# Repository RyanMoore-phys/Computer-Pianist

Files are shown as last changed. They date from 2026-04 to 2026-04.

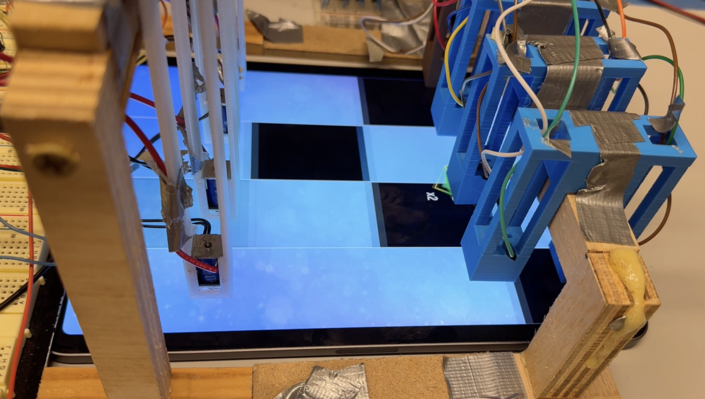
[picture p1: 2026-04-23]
Screenshot.png

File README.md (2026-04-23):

# Computer-Pianist
PianoTiles PhysicalAutoPlayer

The motivation for this project lies in the physical and biological limitations of human
reaction time compared to the processing speed of modern microcontrollers. In a typical
rhythm game environment, such as the mobile game Piano Tiles 2, a player is tasked with
identifying a visual stimulus (a black tile appearing on a white background) and reacting by physically tapping the screen.

For a human, this process involves a complex chain of biological events: optical trans-
duction in the retina, signal propagation through the optic nerve, neural processing in the visual cortex, decision-making in the frontal lobe, and finally, the propagation of motor signals to the muscles in the fingers. The average human reaction time to a visual stimulus is approximately 250 milliseconds. While this is suﬃcient for casual gameplay, it imposes a hard ”speed limit” on performance. Physically, this limits a human player to a maximum frequency of approximately 4–5 Hz (notes per second). As game diﬃculty increases, note density often exceeds this biological bandwidth, making perfect performance physiologically impossible.

This project seeks to overcome these biological constraints by replacing the human neural
pathway with an electronic circuit and software logic. By utilizing a microprocessor (Ar-
duino Uno) operating at a clock speed of 16 MHz, the ”reaction time” can be reduced from
hundreds of milliseconds to mere microseconds. Unlike human nerve impulses, which travel
at approximately 100 m/s, the internal signals of the microcontroller propagate at a significant fraction of the speed of light. This project explores the physics of optoelectronics and electromechanics to create a closed-loop system capable of playing Piano Tiles at speeds that are strictly impossible for a human player, limited only by the physical articulation time of the actuators.

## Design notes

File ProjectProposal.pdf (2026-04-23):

# Project Proposal: The Computer Pianist

### A High-Speed, Reactionary Robot for Rhythm Game Automation Physics 124

### Dylan Dahlke and Ryan Moore

### Feb 10, 2026

## 1 Motivation and Overview

### 1.1 The Limitation of Human Reflexes

The motivation for this project lies in the physical and biological limitations of human

reaction time compared to the processing speed of modern microcontrollers. In a typical

rhythm game environment, such as the mobile game Piano Tiles 2, a player is tasked with

identifying a visual stimulus (a black tile appearing on a white background) and reacting by

physically tapping the screen.

For a human, this process involves a complex chain of biological events: optical trans-

duction in the retina, signal propagation through the optic nerve, neural processing in the

visual cortex, decision-making in the frontal lobe, and finally, the propagation of motor sig-

nals to the muscles in the fingers. The average human reaction time to a visual stimulus

is approximately 250 milliseconds. While this is sufficient for casual gameplay, it imposes a

hard ”speed limit” on performance. Physically, this limits a human player to a maximum

frequency of approximately 4–5 Hz (notes per second). As game difficulty increases, note

density often exceeds this biological bandwidth, making perfect performance physiologically

impossible.

### 1.2 The Robotic Advantage

This project seeks to overcome these biological constraints by replacing the human neural

pathway with an electronic circuit and software logic. By utilizing a microprocessor (Ar-

duino Uno) operating at a clock speed of 16 MHz, the ”reaction time” can be reduced from

hundreds of milliseconds to mere microseconds. Unlike human nerve impulses, which travel

at approximately 100 m/s, the internal signals of the microcontroller propagate at a signifi-

cant fraction of the speed of light. This project explores the physics of optoelectronics and

electromechanics to create a closed-loop system capable of playing Piano Tiles at speeds

that are strictly impossible for a human player, limited only by the physical articulation

time of the actuators.

### 1.3 Project Concept

The ”Computer Pianist” is a non-invasive robotic apparatus designed to play rhythm games

on a capacitive touch-screen device (smartphone or tablet). Unlike software-based ”hacks”

that manipulate the game’s code directly, this project interacts with the device purely

through physical means, mimicking a human player. The system consists of a structural

”bridge” that spans the width of the mobile device. This bridge houses an array of four

optical sensors (the ”eyes”) and four electromechanical actuators (the ”fingers”).

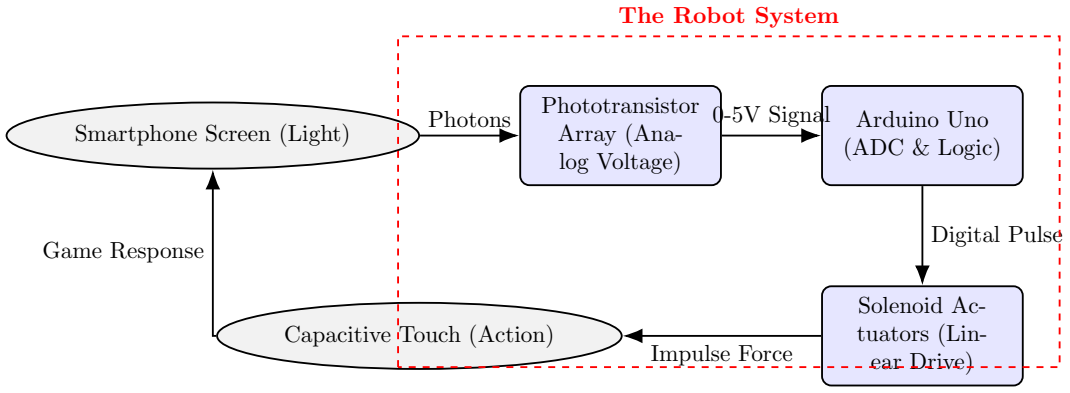
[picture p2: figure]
Smartphone Screen (Light); Phototransistor Array (Ana- log Voltage); Arduino Uno (ADC & Logic); Solenoid Ac- tuators (Lin- ear Drive); Capacitive; Touch (Action); Photons; 0-5V Signal; Digital Pulse; Impulse Force; Game Response; The Robot System

Figure 1: System Data Flow: A closed-loop feedback control system. The robot senses

light (stimulus), processes the signal via the Arduino ADC, and triggers high-speed Solenoid

Actuators to physically strike the screen (response).

### 1.4 Physics and Engineering Goals

The primary goal is to demonstrate the successful integration of analog sensing with digital

control logic. We aim to construct a device that can perform three functions:

Sense: Observe the environment and mathematically describe it. By detecting the

high-contrast transition between the white background and the black game tiles using pho-

totransistors, our project quantizies the changes in light.

Process: Using a microcontroller to interpret these analog voltage changes through the

phototransistors, logic states (Note Present vs. Note Absent) can be used to calculate the

necessary kinematic timing. Translating analog input to an appropriate response is brain

behind our project.

Actuate: Managing a physical response to the change in environment is critical in the case of fast-moving piano tiles. Our process shall trigger a linear solenoid to physically

depress the screen surface using a conductive tip, simulating a finger touch.

This project allows us to apply the skills learned in the first weeks of Physics 124specifi-

cally analog inputs, PWM output, and logic thresholdsto a real-world application involving

feedback loops, hardware interrupts, and precise latency management.

## 2 Functional Definition

This section details the operational logic of the Computer Pianist, defining the system’s

reactions to all foreseeable operating states and stimuli using a Finite State Machine (FSM)

architecture.

### 2.1 The Operational Environment

The device functions by placing a smartphone running a 4-lane rhythm game (e.g., Piano

Tiles) underneath a stationary sensor/actuator bridge. The game presents a scrolling display

where black tiles move from the top of the screen to the bottom at velocity v. The ”hit line”

(where the solenoid plunger contacts the screen) is located at a fixed distance ∆y downstream

from the optical sensors.

### 2.2 Initialization and Calibration State

Upon receiving power, the Computer Pianist enters an Initialization State. Because we

have transitioned to Hardware Comparators for zero-latency detection, the threshold defini-

tion of ”Black” vs. ”White” is no longer calculated by the Arduino, but set physically via

potentiometers.

The Arduino executes a setup() routine to verify the hardware readiness:

1. Safety Lock: The system immediately writes all Solenoid Driver pins LOW to prevent

accidental actuation during startup.

2. Logic Verification: The system reads the four Digital Input pins from the compara-

tors. It assumes the game is on the ”Start” screen (All White). If any pin reads LOW

(detecting ”Black”), it implies a sensor error or miscalibration. The system will hold

in this state until all sensors read HIGH.

3. Confirmation: Once the sensors are verified as ”Idle,” a dedicated status LED blinks three times to indicate that the calibration is valid and the system is transitioning to

the Active State.

S

### 2.3 The Active Sensing Loop

Once calibrated, the system enters the main loop(). However, unlike a standard polling

loop, the ”sensing” is handled asynchronously by the hardware.

Stimulus: A black tile scrolls down the screen.

Hardware Detection: As the leading edge of the tile passes underneath the phototransis-

tor, the reflected light intensity decreases, causing the sensor voltage to drop. This analog

voltage is constantly compared against the reference voltage (Vref ) by the external LM339

Comparator.

Interrupt Trigger: When the sensor voltage dips below Vref (Black Tile), the Comparator

output snaps from HIGH to LOW. This falling edge triggers the Arduino’s Pin Change

Interrupt (PCINT), instantly pausing the main loop to execute the actuation logic defined

in the ISR.

### 2.4 The Actuation Sequence

When Condition B is met, the FSM transitions to the Actuation State for that specific

lane. This is achieved by dedicating four digital pins on the Arduino board, one for each

lane. This sets off three general actions to allow our phototransistors to properly translate

the voltage change into a ”press”. To maximize speed, this sequence operates on a ”Dead

Reckoning” (Open-Loop) principle: we assume the high-speed solenoid will strike the target

at the calculated time without waiting for force-sensor confirmation.

1. Latency Delay: Because the sensors are placed physically upstream from the actu-

ators to prevent occlusion, the robot ”sees” the note early. The software initiates a

timer to wait for the duration ∆t required for the tile to travel to the hit zone, gov-

erned by the kinematics equation (where vscroll is derived from the pre-game calibration

routine):

∆t =

∆y

vscroll

(1)

2. Strike: Once ∆t elapses, the Arduino sends a digital HIGH pulse to the solenoid

driver. The solenoid extends linearly to impact the screen, eliminating the rotational

inertia delay associated with servo motors.

3. Retract: The solenoid is held active for a minimum duration (thold ≈ 20ms) to ensure

the capacitive screen registers the touch, then the signal is cut to allow the return

spring to retract the plunger.

### 2.5 Handling Operating States and Errors

Signal Hysteresis (Debouncing): If the sensor detects noise or a screen scratch, it might

trigger false positives. The logic includes a ”Cooldown Timer” that prevents a single actuator

from firing twice within a 50ms window (Subject to empirical testing during the high-speed

phase).

Game Over State: If the robot misses a tile, the game freezes. The sensors see a static

image, and the code inherently treats this as ”no change,” keeping the actuators idle. No

dedicated ”kill switch” is required.

Ambient Light Shift: Shadows falling across the phone may trigger false detections.

We mitigate this mechanically by shrouding the sensors rather than increasing software

complexity in the first iteration.

Phototransistor Overlap: Without a proper structure, it may be true that multiple

phototransistors detect the same tile. To mitigate this, we shall construct a physical structure

to block interference from external lanes.

### 2.6 Theoretical Latency Budget Analysis

To justify the necessity of the ”Look Ahead” predictive algorithm, we must characterize the

total system latency (Tsys). In a reactive system, the total time from stimulus to action is

the sum of component delays:

Tsys = Trise + Tlogic + Tmech | (2)

The phototransistor has a finite response time to a change in photon flux, typically

≈ 15µs. Previously, relying on the Arduino ADC introduced a sampling delay of TADC ≈

104µs. Following the feedback to optimize for speed, we have replaced ADC polling with an

interrupt-driven architecture using analog comparators. This replaces the slow conversion

time with a negligible comparator propagation delay and Interrupt Service Routine (ISR)

latency (TISR ≈ 5µs), reducing electronic latency by over 95%.

Furthermore, to address the articulation limits of servo motors, we have switched to high-

speed solenoid actuators. While significantly faster than the servo’s travel time (25ms),

the solenoid plunger still possesses inertia and inductance that create a mechanical delay

(Tmech ≈ 10 − 15ms). Since Tmech remains orders of magnitude larger than the electronic

delays, it is the dominant term. The ”Look Ahead” variable ∆t allows us to effectively

negate this physical delay by firing the solenoid before the note reaches the hit line.

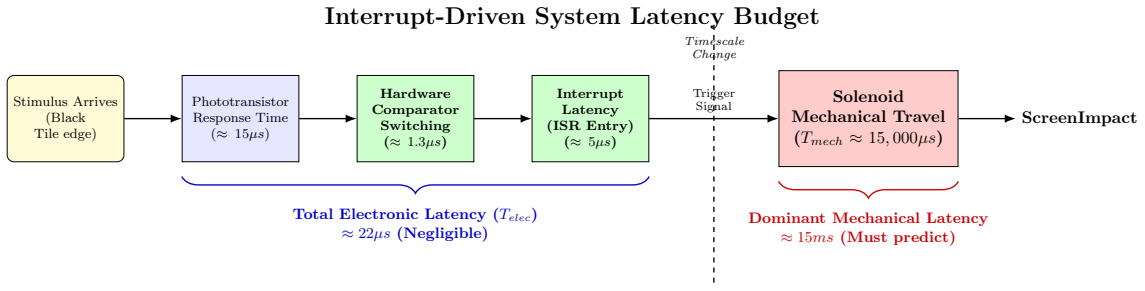
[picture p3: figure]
Stimulus Arrives (Black Tile edge); Phototransistor Response Time (≈ 15µs); Hardware Comparator Switching (≈ 1.3µs); Interrupt Latency (ISR Entry) (≈ 5µs); Solenoid Mechanical Travel (Tmech ≈ 15, 000µs); ScreenImpact; Trigger Signal; Total Electronic Latency (Telec) ≈ 22µs (Negligible); Dominant Mechanical Latency ≈ 15ms (Must predict); Timescale Change; Interrupt-Driven System Latency Budget

Figure 2: System Latency Budget (Interrupt Architecture): A timeline comparison

of signal propagation delays. By switching from ADC polling to hardware comparators and

interrupts, electronic latency (Telec) is reduced to negligible microseconds. The mechanical

transit time of the solenoid (Tmech ≈ 15ms) now completely dominates the system, necessi-

tating the predictive ”Look Ahead” algorithm.

## 3 Sensors

### 3.1 Theoretical Basis of Sensing: Optoelectronic Physics

To understand the operation of the ”eyes” of the Computer Pianist, we must examine the

solid-state physics governing the chosen phototransistors. We are utilizing silicon-based NPN

phototransistors which rely on the internal photoelectric effect to modulate current flow.

### 3.1.1 The Band Gap Mechanism

The core mechanism of detection is the generation of electron-hole pairs within the semi-

conductor material. Silicon has a band gap energy (Eg) of approximately 1.12 eV at room

temperature. When a photon from the smartphone screen strikes the exposed Base-Collector

junction of the phototransistor, it is absorbed if its energy (Eph) exceeds this band gap:

Eph = hν =

hc
λ
≥ 1.12 eV | (3)

Where h is Planck’s constant, c is the speed of light, and λ is the wavelength. The white

light emitted by the smartphone LED backlight is a composite spectrum rich in peaks at

460nm (Blue) and broad phosphorescent emission from 500nm–700nm. These wavelengths

correspond to photon energies well above 1.12 eV, ensuring efficient absorption and the

promotion of electrons from the valence band to the conduction band.

### 3.1.2 Transistor Amplification (β)

A key design decision was choosing a phototransistor over a simple photodiode. While

a photodiode generates a small photocurrent (Iphoto) directly proportional to the incident

light, this current is typically in the range of microamperes (µA), which is difficult to detect

without a dedicated Op-Amp pre-amplifier stage.

The phototransistor solves this by using the Bipolar Junction Transistor (BJT) architec-

ture for intrinsic amplification. The photon-generated carriers in the Base-Collector depletion

region act effectively as a ”base current” (Ib). In the active region of operation, the transis-

tor amplifies this current by its forward current gain factor, β (or hF E), which is typically

between 100 and 1000 for standard devices. The resulting collector current (Ic) is given by:

Ic ≈ β · Iphoto | (4)

This internal gain allows us to drive the Comparator inputs directly without complex

amplification circuitry, simplifying our electrical footprint.

### 3.1.3 Voltage Divider Transfer Function

To convert this variable current (Ic) into a voltage (Vout) usable by the hardware interrupts,

we place the phototransistor in a Common-Emitter voltage divider configuration.

We connect the Emitter to Ground and the Collector to the +5V rail via the fixed

resistor. The node between the Collector and the resistor is our output Vout. This output is

fed directly to the inputs of the LM339 Analog Comparator. According to Kirchhoff’s laws:

Vout = Vcc − (Ic · Rf ixed) | (5)

Substituting the optical relationship, we see the transfer function:

Vout = 5V − (β · Iphoto · Rf ixed) | (6)

This equation dictates the switching logic for our interrupts:

+5V

Rf ixed (10kΩ)

Vout (To Arduino Pin A0)

Vout

Light (hν)

Figure 3: Optical Sensor Circuit: The NPN phototransistor in a common-emitter volt-

age divider. Note the Inverse Logic: As light intensity increases (White), Current (Iphoto)

increases, pulling Vout LOW. When a Black Tile arrives (Dark), Current drops, allowing Vout

to be pulled HIGH (5V ).

- High Light (White Background): Iphoto is high. The voltage drop across Rf ixed is

large. Vout is pulled Low (< Vref ), keeping the Comparator Output LOW.

- Low Light (Black Tile): Iphoto approaches zero (dark current). The voltage drop

across Rf ixed minimizes. Vout is pulled High (> Vref ), causing the Comparator to switch

HIGH and trigger the Interrupt.

### 3.2 Sensing the Physical touch with Force Sensors

No Pianist is complete without a good set of fingers. After sensing changes in light, we aim

to understand the location of each finger (on or off the screen) and respond appropriately.

To do so, force sensors will be applied to each finger tip.

Dead Reckoning vs. Closed Loop: While we primarily rely on Dead Reckoning for

speed (as detailed in Section 2.4), we can also implement force sensors to test this assumption.

Ideally, the force sensors will provide ”Closed Loop” confirmation that a hit occurred. If we

find that the sensors introduce too much latency, we will revert to pure Dead Reckoning and

utilize the force sensors strictly for static calibration and ”Game Over” state detection.

### 3.2.1 Force Sensor in Circuit

Based on the force sensor provided in the shopping list, we will be using a FSR 400 Series

Round Face Resistor. Below is an diagram showing how we will use the force sensor.

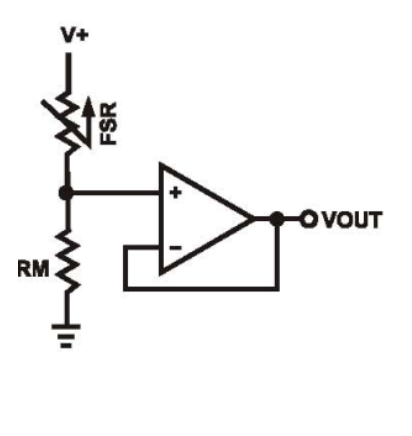
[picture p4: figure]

Figure 4: Diagram of our use of each FSR 400 Series Round Face Resistor

We will supply a constant Voltage across the Force Sensor and record the value for Vout

and Vin using data cables hooked up to our Arduino board. We will also include an op-Amp

to ensure we don’t overload our arduino with current and it provides a simple voltage divider

set-up allowing us to determine the resistance across the force sensor at any time. We will

attach one data cable before force sensor and another at the end of the op-Amp.

### 3.2.2 Resistance

Based on the schematics for the part, the resistance without any pressure will be upwards

of 10MΩ. When force is applied to the force sensor, the actuated resistance will be less than

the non-actuated resistance, leading to a rise in voltage at Vout.

### 3.2.3 To the Arduino

By taking a measurement Vout at this non-actuated state, we record the lowest voltage that

will be recorded at Vout. In our code, we can determine the state of each finger by comparing

Vout to a non-actuated Vout. We should expect Vout to be greater at a ”pressed” state. There

will likely be some noise with our measurements and force sensing. We must account for and

determine a range based on experimental testing.

### 3.3 Electronic Implementation

Implementing the theoretical model described above, we will construct the physical voltage

dividers using 10kΩ fixed resistors.

- Circuit Topology: Each phototransistor is placed in series with a fixed resistor (nom-

inally 10kΩ) between the +5V rail and Ground. The junction between the phototran-

sistor and the resistor is connected to the Non-Inverting Input of the Comparator.

- Operation: As the light intensity reflected from the screen changes (White Back-

ground → Black Tile), the effective resistance of the phototransistor changes. This

shifts the voltage at the junction point.

- Readout: The voltage is fed into an **LM339 Quad Comparator**. Instead of relying

on the Arduino’s slow ADC polling (≈ 100µs), the comparator provides a hardware-

level digital transition in < 1µs when the voltage crosses the threshold set by the

tuning potentiometers.

## 4 Electrical Considerations

### 4.1 Microcontroller Interface

The central processing unit will be an Arduino Uno R3.

- Inputs: As detailed in the Sensors section, pins A0 through A3 are dedicated to the

four sensor inputs.

- Outputs: We require four Digital I/O pins to control the solenoid drivers. We will

utilize Digital Pins 3, 5, 6, and 9. Unlike servos which require PWM, these pins will

simply toggle HIGH/LOW to energize the MOSFET gates. We will explicitly avoid

using Digital Pins 0 and 1, as these are reserved for Serial communication.

### 4.2 Power Distribution and Isolation

A critical electrical consideration is the power draw of the actuators. Solenoids are high-

current inductive loads. A standard push-pull solenoid can draw current spikes in excess of

1A when initially energized, far exceeding the limit of the Arduino’s I/O pins (40mA).

- The Issue: The Arduino Uno’s on-board 5V regulator cannot supply the high current

required for four simultaneous coils. Furthermore, connecting a solenoid directly to a

microcontroller would destroy the chip due to inductive voltage spikes (back-EMF).

- The Solution: We will implement a split power rail system with a dedicated driver

stage.

– Logic Power: The Arduino will be powered via the USB connection to a laptop.

– Actuator Power: The four solenoids will be powered by a Benchtop DC

Power Supply set to 6.0V.

– Driver Circuit: As shown in Figure 5, we will use an N-Channel MOSFET to

act as a high-current switch. A ”Flyback Diode” (1N4001) is placed in parallel with the solenoid to safely dissipate the magnetic energy when the field collapses,

protecting the rest of the circuit.

– Common Ground: The negative terminal of the power supply is tied to the

Arduino GND to provide a reference for the MOSFET gate signal.

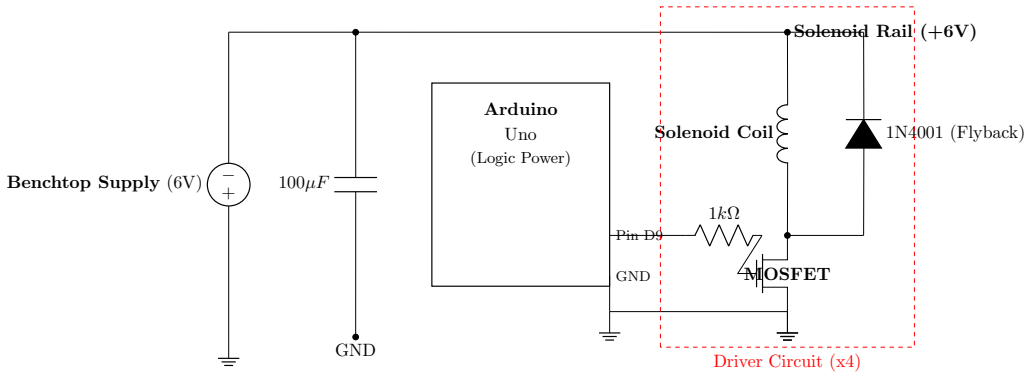
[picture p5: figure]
Benchtop Supply (6V) +; GND; Solenoid Rail (+6V); Arduino; Uno; (Logic Power); Pin D9; MOSFET; Solenoid Coil; 1N4001 (Flyback); Driver Circuit (x4)

Figure 5: Solenoid Driver Schematic: The high-current Solenoid Rail (6V) is isolated

from the logic. The Arduino toggles a MOSFET to complete the circuit. A flyback diode

protects against inductive voltage spikes.

### 4.3 Signal Integrity and Noise Suppression

While the split power rail protects the microcontroller, the inductive nature of the solenoid

coils introduces a secondary risk: Electromagnetic Interference (EMI).

When a solenoid de-energizes, the collapsing magnetic field generates a high-voltage spike

(back-EMF). To mitigate this:

- Flyback Diodes: We will place a 1N4001 diode in parallel with each solenoid coil

(Cathode to +V) to safely dissipate the back-EMF current, protecting the MOSFETs.

- Bulk Capacitance: A large electrolytic capacitor (100µF) will be placed across the

power rails to smooth out voltage dips caused by the sudden current demand of the

solenoids firing.

## 5 Mechanical Considerations

### 5.1 Detailed Mechanical Design: The Sensor-Actuator Bridge

### 5.1.1 Structural Requirements and Physics of Stability

The primary mechanical constraint of the Computer Pianist is rigidity relative to the optical

target. The optical sensors have a viewing angle of approximately 20◦
. At a height of 20mm

above the screen, the ”spot size” seen by the sensor is roughly 7mm in diameter. The

game tiles are approximately 15mm wide. This implies that if the bridge structure vibrates

or shifts by more than ±4mm laterally during operation, the sensors may lose alignment

with the game lanes, resulting in false negatives. The actuation of the solenoids creates a

sharp vertical mechanical impulse. A solenoid plunger snapping down in < 15ms produces a

distinct recoil. If the bridge mass is too low, these impulses will excite resonant frequencies,

causing the ”eyes” to jitter.

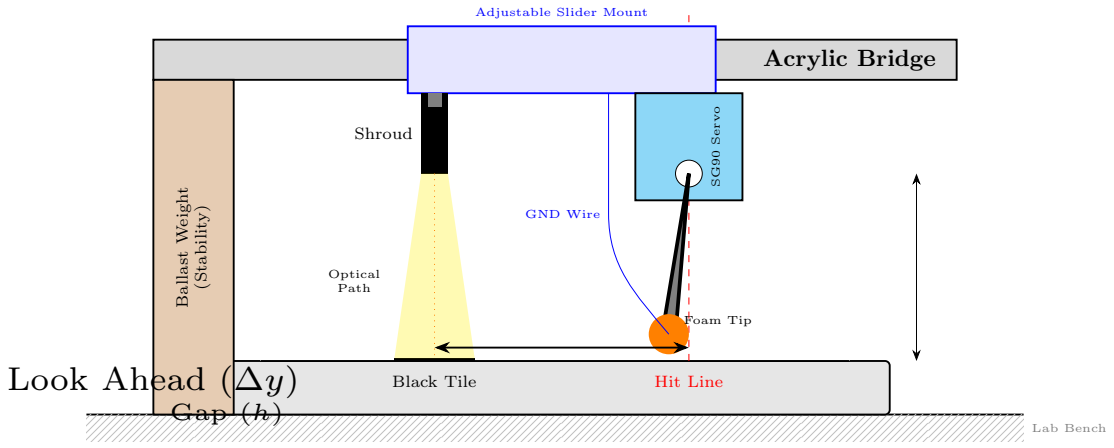
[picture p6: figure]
Lab Bench; Black Tile; Hit Line; Acrylic Bridge; Ballast Weight; (Stability); Adjustable Slider Mount; Shroud; Optical Path; SG90 Servo; Foam Tip; GND Wire; Look Ahead (∆y); Gap

Figure 6: Mechanical Side Elevation: The assembly features a rigid acrylic bridge span-

ning the phone. Key elements include the ”Look Ahead” distance (∆y) for latency compen-

sation and the adjustable slider mount for aligning with variable lane widths.

- Ballast Integration: We will implement weighted base supports to increase the

inertia of the base (I =

∑mr²
), making it resistant to the vertical recoil of the

actuators.

- Friction Maximization: To prevent the entire unit from ”walking” across the table

due to vibration, the bottom surface will have a mat to prevent slippage.

### 5.1.2 Construction Methodology

We will utilize the physics machine shop’s band saw and drill press for the primary fabrica-

tion, adhering to the safety protocols outlined in the class guide.

- The Main Span: We will cut a strip of 0.25-inch acrylic/wood sheet measuring 25cm

x 4cm.

- Sensor Shrouding: To further isolate the optical path, we will fabricate ”blinders” for

the phototransistors. We will encase the sides of the phototransistors, leaving only the

tip exposed. This effectively creates a ”tunnel” for the light, reducing the acceptance

angle and preventing adjacent white lanes from triggering a false ”black” detection on

a neighboring sensor.

### Smartphone Screen Surface

### Lane 1 Lane 2 (Black) Lane 3

### Sensor 2 (Target)

Restricted FOV

Unshrouded sensor
would see Lane 2
(Crosstalk Risk)

Figure 7: Optical Isolation: Without shrouding, the sensor’s wide field of view (dotted

lines) would detect tiles in adjacent lanes, causing false triggers. The opaque shroud restricts

detection strictly to the target lane (red dashed lines).

### 5.2 The Actuators

### 5.2.1 Electromechanical Theory: Solenoid Dynamics

To achieve reaction times faster than the human hand, we have replaced the servo motors

with Linear Solenoid Actuators. Unlike a servo which requires a complex Pulse Position

Modulation (PPM) signal to set an angle, a solenoid is a binary device governed by the

principles of electromagnetism.

Physics of Actuation (Lorentz Force)

The actuator consists of a wound copper coil and a ferromagnetic steel plunger. When

current (I) flows through the coil, it generates a magnetic field (B) according to Ampere’s

Law. This field induces a magnetic flux that seeks to minimize the reluctance of the optical

path, pulling the plunger into the coil center with a force (F) described largely by:

F ∝

(N · I)

2
g

2

(7)

Where N is the number of turns, I is the current, and g is the air gap distance.

- Digital Control: Since the device is binary, we discard the Servo.h library. Instead,

we drive the solenoid using a MOSFET Transistor controlled by a simple Digital

High/Low signal from the Arduino.

- Speed Advantage: Without the need to decode a PWM signal or drive a gear train,

the solenoid plunger accelerates instantly upon energization, reducing the mechanical

latency (Tmech) from ≈ 25ms (Servo) to ≈ 10 − 15ms (Solenoid).

Feasibility Analysis:

Solenoids typically exert maximum force when the air gap (g) is small. To ensure the ”finger”

has enough force to tap the screen from a hover height of 2mm, we will overdrive the coil with

6V (within thermal limits for short bursts). The lack of gears means there is zero backlash,

providing a cleaner, sharper impact event compared to the plastic gears of an SG90.

### 5.2.2 Actuator Implementation

Based on the feasibility analysis, we will implement the actuation system using four Open-

Frame Linear Solenoids.

- Physical Mounting: The solenoids will be mounted vertically to the main acrylic

span using a custom 3D-printed bracket. This orients the plunger perpendicular to the

screen surface, allowing for direct linear action without complex linkages.

- Stroke Calibration: Unlike servos which must be calibrated to specific angles,

solenoids are binary. We will adjust the vertical height of the bridge such that the

”Hover” state (Plunger Retracted) holds the tip 2mm above the glass, and the ”Strike”

state (Plunger Extended) allows the foam to compress slightly against the screen.

- Capacitive Coupling (The ”Touch” Mechanism): Standard steel plungers are

electrically conductive but may not trigger the screen without a larger surface area.

1. We will affix a block of conductive anti-static foam (recycled from IC packaging)

to each plunger tip to increase the contact area and cushion the impact.

2. Since the plunger is metal, we can ground the solenoid casing directly to the

system’s common ground rail. This turns the entire actuator assembly into a

low-impedance capacitive probe, ensuring that the smartphone’s touch controller

detects a valid input upon contact.

## Smartphone Screen Glass

Solenoid Casing
(Metal / Conductive) Steel Plunger

To Circuit GND

Electrical Path:
Casing → Plunger

Conductive Foam

Virtual Capacitor

∆Ctouch

Figure 8: Capacitive Touch Mechanism (Solenoid): Unlike the previous servo design,

the solenoid plunger is solid steel (conductive). By grounding the solenoid casing to the

circuit’s common ground, the entire assembly becomes an extension of the ground plane.

The conductive foam tip completes the capacitive circuit (∆Ctouch) upon impact.

### 5.2.3 Custom 3D Printed Fingers

We have designed custom ”finger” extensions using SolidWorks (Figure 9).

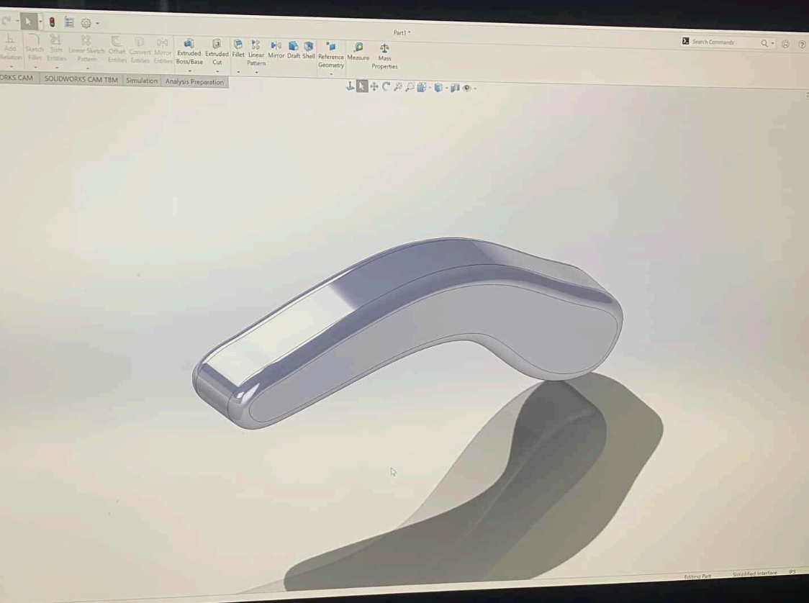
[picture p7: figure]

Figure 9: CAD Model of Actuator Finger: The custom extension features a curvature to

clear the edge of the smartphone and an edge tip sized specifically to receive the conductive

foam pad.

- Fabrication: The fingers will be 3D printed with material offering a high stiffness-

to-weight ratio, ensuring the fingers are rigid enough to transmit force without adding

excessive mass to the solenoid plunger, which would slow down the retraction speed.

- Assembly: The high-density conductive foam will be adhered to the flat tip of the

printed finger. The grounding wire will be routed along the spine of the finger and

inserted into the foam, completing the capacitive circuit to the common ground rail.

## 6 Interfaces

### 6.1 Microcontroller Pinout Strategy

The interface design maximizes the efficiency of the Arduino Uno’s ATmega328P architec-

ture. To support the Interrupt-Driven architecture, we have re-assigned pins to leverage Pin

Change Interrupts (PCINT) and direct Digital I/O.

Pin | Function | Description
D2, D4, D7, D8 | Digital Input | Comparator Outputs (Interrupt Triggers)
D3, D5, D6, D9 | Digital Output | Solenoid MOSFET Driver Gates
D0 (RX), D1 (TX) | UART | Serial Communication for Debugging
5V / GND | Power Rails | Logic Power for Sensors

Table 1: Updated System Pin Assignment Table

### 6.2 Sensor Interface (Comparator & Interrupts)

To achieve the microsecond-level reaction times required, we bypass the Arduino’s slow

internal ADC in favor of a hardware-based thresholding system.

- Comparator Circuit: Each phototransistor voltage is fed into the non-inverting

input of an LM339 Analog Comparator. The inverting input is connected to a

reference voltage (Vref ) set by a precision multi-turn potentiometer.

- Zero-Latency Detection: Instead of the CPU spending 100µs to digitize an analog

signal (ADC conversion time), the comparator switches its output LOW immediately

when the light level drops below the threshold. The propagation delay of the LM339

is approx. 1.3µs, effectively instantaneous compared to the game speed.

- Interrupt Trigger: The comparator outputs are routed to Digital Pins configured

for Pin Change Interrupts (PCINT). This generates a hardware interrupt request

(IRQ) exactly when the note arrives, waking the processor instantly to handle the

event.

### 6.3 Digital Interface (Actuation)

The four solenoid drivers connect to Digital Pins 3, 5, 6, and 9.

- Direct Digital Drive: Unlike servos which require a continuous 50Hz PWM signal

to hold position, the solenoids operate in a simple ”One-Shot” mode. We configure

these pins as standard Digital Outputs.

- Timer-Controlled Pulse: When the interrupt fires, we do not use delay() to hold

the solenoid ON. Instead, we trigger a Hardware Timer to pull the pin HIGH, count

exactly 20ms, and then pull it LOW via an interrupt. This ensures the solenoid

actuation duration is precise and does not block the main CPU loop.

## 7 Software

### 7.1 Control Logic Overview

The software will be developed in C++ using the Arduino IDE. The central architectural

challenge is managing four independent game lanes simultaneously without blocking the

processor. A standard linear approach using ‘delay()‘ would render the robot ”blind” to

events in Lane 2 while it is pressing a button for Lane 1.

To resolve this, we will implement an Interrupt-Driven Architecture utilizing hard-

ware timers. Rather than continuously polling the sensors in a loop (which consumes CPU

cycles and introduces jitter), we will configure the analog comparators to trigger an Ex-

ternal Interrupt (ISR) immediately upon detecting a note. Once triggered, the ISR will

utilize a Hardware Timer to precisely schedule the solenoid actuation delay (∆t) and du-

ration (thold), ensuring that the mechanical response is decoupled from the main processor

loop.

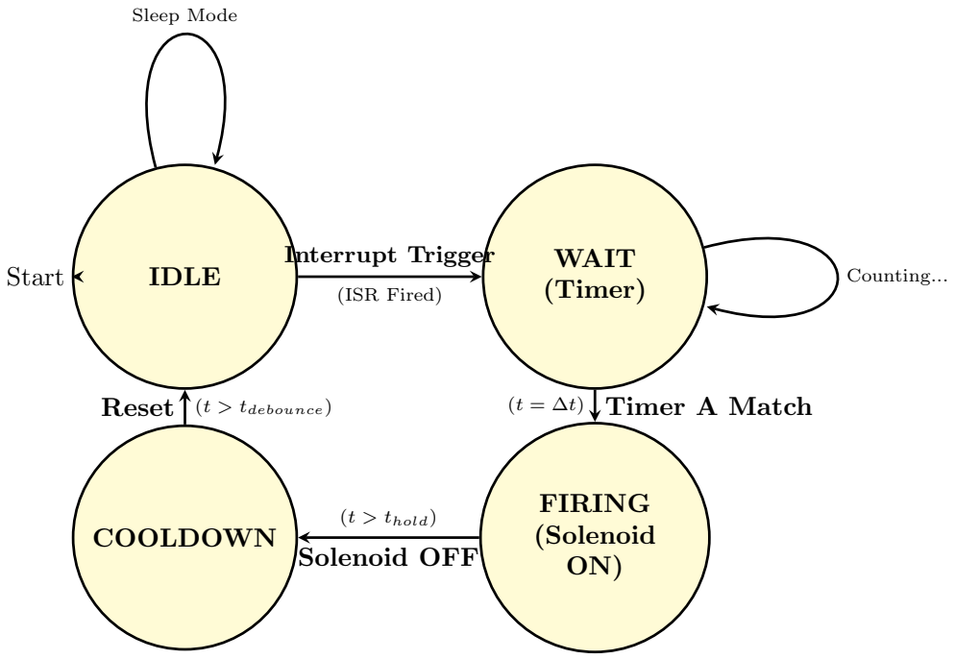
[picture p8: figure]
IDLE; WAIT (Timer); FIRING (Solenoid ON); COOLDOWN; Interrupt Trigger; (ISR Fired); Timer A Match; Solenoid OFF; (t > thold); Reset; (t > tdebounce); Sleep Mode; Start; Counting...

Figure 10: Interrupt-Driven State Machine: The logic flow for a single lane. Instead

of polling, the system remains IDLE until a hardware interrupt triggers the Timer. The

Solenoid is fired via a ”One-Shot” timer pulse, ensuring precise duration without blocking

the CPU.

### 7.2 Calibration and Startup Routine

Since the voltage thresholds are now set via hardware potentiometers (see Section 6.2), the

software does not need to calculate Vthresh. Instead, the ‘setup()‘ routine performs a **Safety

Verification**:

1. Logic Check: The system reads all four Digital Input pins. It verifies that all com-

parators are outputting a Logic HIGH (IDLE state). If any pin is LOW (indicating

a sensor is stuck or covered), the system enters an Error State and flashes the status

LED.

2. Solenoid Retract: The system ensures all solenoid pins are written LOW to prevent

accidental firing during startup, which could damage the screen or overheat the coils.

### 7.3 The Interrupt-Driven Logic

The core logic is split between the Interrupt Service Routine (ISR) (which handles the critical

”Trigger” event) and the Main Loop (which handles timing and solenoid release).

Listing 1: Pseudocode for Interrupt-Driven Lane Logic

// Global Volatile Variables ( Shared between ISR and Loop )

volatile bool triggered = false ;

volatile unsigned long detectTime = 0;

// 1. THE INTERRUPT ( Runs instantly when Comparator goes LOW )

void ISR_Lane1 () {

if ( state == IDLE ) {

detectTime = micros () ; // Capture exact microsecond

triggered = true ; | // Flag main loop to handle it

state = WAIT_LATENCY ;

}

}

// 2. THE MAIN LOOP (Non - Blocking )

void updateLane () {

unsigned long currentMicros = micros () ;

switch ( state ) {

case WAIT_LATENCY :

// Wait for ’Look Ahead ’ delay ( delta_t )

if ( currentMicros - detectTime >= TRAVEL_DELAY ) {

digitalWrite ( SOLENOID_PIN , HIGH ) ; // FIRE !

strikeTime = currentMicros ;

state = FIRING ;

}

break ;

case FIRING :

// Hold Solenoid ON for 20 ms to ensure touch registration

if ( currentMicros - strikeTime >= HOLD_DURATION ) {

digitalWrite ( SOLENOID_PIN , LOW ) ; // RELEASE

cooldownStart = currentMicros ;

state = COOLDOWN ;

}

break ;

case COOLDOWN :

// Ignore interrupts for 50 ms to prevent double - hits

if ( currentMicros - cooldownStart >= DEBOUNCE ) {

state = IDLE ;

triggered = false ; // Reset flag

}

break ;

}

}

### 7.4 Libraries and Timing Architecture

We explicitly discard the <Servo.h> library, as solenoids are binary devices that do not

require a 50Hz PWM carrier signal.

- Microsecond Precision: Instead of standard millis(), we utilize the micros()

counter and hardware interrupts. This allows us to track the note’s position with a

resolution of 4µs (on the Arduino Uno), which is critical when the scroll speed exceeds

50cm/s.

- Port Manipulation (Optimization): To further reduce latency, we may bypass

the standard digitalWrite() function (which takes ≈ 5µs) and write directly to the

ATmega328P’s PORTD registers. This allows us to trigger the solenoid driver in a

single clock cycle (62.5ns).

## 8 Testing Plan

### 8.1 Phase 1: Sub-System Verification

Testing will proceed in a modular fashion to verify the new hardware architecture.

- Comparator Tuning & Digital Logic Test: Since we are using hardware compara-

tors, we cannot plot ”raw analog values.” Instead, we will monitor the Digital Input

pins via the Serial Monitor.

– Procedure: We will pass a black test card under the sensor while adjusting the

multi-turn potentiometer on the LM339 comparator circuit.

– Success Criteria: The Serial Monitor must report a clean, instant transition from

Logic HIGH (White) to Logic LOW (Black) without ”flickering” (bouncing) at

the transition edge.

- Solenoid Driver & Thermal Test: We will run a ”Rapid Fire” routine that toggles

all four solenoids at 5Hz (standard gameplay speed) for 60 seconds.

– Objective: Verify that the 6V Power Rail does not sag below 5.5V during the cur-

rent spikes. Crucially, we will use an IR thermometer to verify that the MOSFET drivers and Solenoid Coils remain within safe thermal limits (< 50◦C).

### 8.2 Phase 2: Integration and Latency Tuning

Once hardware is verified, we will close the loop using a controlled video test.

### 8.3 Phase 2: Integration and Latency Tuning

Once hardware is verified, we will close the loop using a controlled video test.

- Static Latency Calibration: We will set a hard-coded delay (∆t) based on our

theoretical calculation (Equation 2). We will record the robot playing a standard level

using a smartphone camera at 240 fps (Slow Motion). By counting frames between the

target line arrival and the solenoid impact, we can calculate the exact timing error (δt)

and adjust the ‘travelDelay‘ variable to compensate for electromechanical inductance.

- Variable Velocity Verification (The ”Simulator” Test): To satisfy the require-

ment of testing at different speeds scientifically, we cannot rely on the random pacing

of the commercial game. We will place the robot over a high-refresh-rate monitor

running a custom scrolling simulator (coded in Python/Processing). This allows

us to ”program the screen” to validate performance at distinct velocity tiers:

– Tier 1 (Cruising): 1 notes/sec (Standard game start speed).

– Tier 2 (Human Speed): 2 notes/sec (Mid-game speed).

– Tier 3 (Stress): 5+ notes/sec (Approaching mechanical limits).

- Acceleration Tracking: Since Piano Tiles speeds up continuously, we will program

the simulator to ramp the scroll velocity (v(t) = v0 + at) to verify that the robot’s

”Look Ahead” logic holds true even as ∆t shrinks dynamically.

- Prediction: With the switch to Solenoids, we eliminate the 60ms servo travel time. We

expect the thermal and inductive limits of the solenoid coils (approx. 15ms extend/re-

tract cycle) to raise our ceiling to ≈ 30 − 40 notes per second per lane.

## 9 Safety

### 9.1 Electrical Safety

While the project operates at Extra-Low Voltage (< 12V), the use of high-current inductive

loads introduces specific risks.

- Short Circuit Prevention: The high current capability of the solenoid power rail

means a VCC-to-GND short could rapidly heat wiring. We will mitigate this by setting

the Current Limit (CC) on the power supply to 2.0A and insulating all soldered joints.

- Inductive Kickback Protection: Solenoids generate high-voltage spikes (Back-

EMF) when de-energized. It could help to install flyback diodes in parallel with each

coil to clamp these spikes, preventing damage to the MOSFETs or the Arduino.

- Polarity Check: We will color-code all power leads (Red for VCC, Black for GND) to

prevent reverse-polarity connections, which would destroy the MOSFET driver circuits.

### 9.2 Mechanical and Device Safety

- Pinch Points: The solenoid plungers oscillate rapidly (f > 5Hz). While the linear

force is low (≈ 2 − 5N), it is sufficient to pinch skin. We will route all cabling through

the hollow sections of the bridge, keeping wires clear of the moving plungers.

- Device Protection (Smartphone): The most significant financial risk is damage to

the smartphone/tablet screen.

– Soft Impact: The tips of the plungers are cushioned with compressible conductive

foam, ensuring that even a maximum-force impact will not crack the glass.

– Thermal Watchdog (Software Limit): Unlike servos, solenoids heat up rapidly if

left energized. We will implement a ”Max On-Time” safety check in the ISR: if

a solenoid remains active for > 100ms (due to a software crash), the system will

force the pin LOW to prevent coil burnout.

– Passive Emergency Stop: The solenoids feature an internal return spring. In the

event of power loss, USB disconnection, or code failure, the plungers automatically

retract to the safe ”Hover” position, physically decoupling them from the screen.

## 10 Parts, Reusability, and Shopping List

### 10.1 Components on Hand (University Inventory)

We will leverage existing laboratory stock to minimize costs and waste.

- Arduino Uno R3: The primary microcontroller platform.
- Passive Components: We will utilize lab stock for all 10kΩ pull-up resistors, 220Ω

LED current-limiting resistors, and hookup wire.

- Structural Material: The bridge chassis will be fabricated entirely from scrap acrylic

and plywood found in the physics workshop bins.

- Phototransistors: We will be using in-house PT5529/L2-F Phototransistors.
- Benchtop Power Supply: Variable DC power supply available in the lab to drive

the high-current solenoid rail.

### 10.2 Components to Purchase (Bill of Materials)

We have identified specific components that require purchasing to ensure high reliability and

future reusability for the department.

Table 2: Project Bill of Materials

Component | Qty | Cost | Technical Justification & Reusability
Linear Solenoid (5V/6V) | 2 (We have 2) | ≈$20 | Justification: Replaces servos to eliminate mechanical latency (Tmech < 15ms). Reusability: High-speed linear actuators useful for future physics demos. Amazon (B0B4DFJTHX) (https://www.amazon.com/dp/B0B4DFJTHX)
PT5529B/L2-F Phototransistors | 4 | $0 | Justification: Chosen over LDRs for microsecond-scale rise times required for high-speed game detection. (In-house).
FSR 400 Force Sensors | 4 | $25 | Justification: Required to determine moment of contact and location. https://www.dfrobot.com/product-614.html (https://www.dfrobot.com/product-614.html)

Continued on next page

Table 2 – continued from previous page

Component | Qty | Cost | Technical Justification & Reusability
Conductive Foam | 1 | $16 | Justification: Provides vari-able resistance contact for capac-itive screens. https://a.co/d/dVHOCnV (https://a.co/d/dVHOCnV)
Total | | ≈$61

## 11 Schedule and Milestones

### 11.1 Overview

We have allocated approximately 12 hours per week for this project, split between individual

component testing and joint integration sessions in the physics lab. The schedule is designed

to front-load the mechanical construction to allow maximum time for software tuning (la-

tency compensation) in the final weeks, as we anticipate the timing calibration to be the

most time-consuming task.

### 11.2 Weekly Breakdown

Table 3: Project Execution Schedule

Week / Dates | Phase & Activities | Key Dates & Milestones
Week 1 (Feb 2 – Feb 8) | Mechanical Construction Fabricate acrylic/wood ”Bridge.” Mount sensors and solenoids. Align assembly with phone screen. | Feb 3: PROPOSAL DUE. Feb 4: Proposal Feedback. Milestone: Bridge assembled.
Week 2 (Feb 9 – Feb 15) | The ”One Lane” Test Code single-lane logic (∆t calibra-tion). Verify ”Look Ahead” math. | Feb 10: MIDTERM. Feb 11: Lab 4 Report / Up-dated Proposal Due.
Week 3 (Feb 16 – Feb 22) | Full Integration Scale code to 4 lanes. Implement Start-up Calibration routine. Final-ize cable management. | Milestone: Full 4-lane au-tonomous operation (beta).
Week 4 (Feb 23 – Mar 1) | Optimization & Check-in Stress testing at high speeds. Me-chanical vibration analysis. Fine-tune thresholds. | Feb 25: MID-PROJECT CHECK-IN. Milestone: Working Demo.
Week 5 (Mar 2 – Mar 8) | Advanced Features General trouble-shooting and a week to breath. Try to implement ”Reach Goals” (e.g., Automatic Latency Calibration or Sustain Logic). Re-fine FSM logic. | Milestone: System feature complete.

Continued on next page

Table 3 – continued from previous page

Week / Dates | Phase & Activities | Key Dates & Milestones
Week 6 (Mar 9 – Mar 15) | Documentation & Polish Film demonstration video. Write final project report. Final code cleanup and commenting. | Milestone: Video filmed, Re-port drafted.
Week 7 (Mar 16 – Mar 22) | Final Presentation Final system check. Charge power supply/batteries. Presentation preparation. | Mar 17: FINAL DEMO (8:00am – 11:00am).

## 12 Mid-Project Deliverables (Due Feb 25)

For the mid-project check-in, we will demonstrate the core functionality of the hardware and

the viability of the sensing logic. Given the complexity of integrating four parallel analog

channels, we will focus our live demonstration on a single lane to prove the physics, while

showing mechanical readiness for the full system. Specifically, we will deliver:

- Mechanical Assembly: The complete ”Bridge” structure will be built, with all 4

solenoids and 4 sensors physically mounted, wired, and aligned over the phone.

- Sensing Integration: We will visualize the Digital Logic stream via the Serial Plot-

ter. Since the comparators output a binary 0 or 1, we will demonstrate clean, crisp

transitions (no flickering) when a tile passes, verifying that the hardware sensitivity

knobs are correctly tuned.

- Actuation Demo: We will demonstrate at least one single finger successfully tap-

ping a tile in response to a sensor input (The ”One Lane” Test). This proves the

closed-loop latency management is functioning.

Note: By prioritizing the perfection of a single lane, we establish a stable standard for

timing and sensitivity. Once this logic is verified, scaling the code to the remaining three

lanes is a matter of software iteration rather than physical reconstruction.

## 13 Comprehensive Risk Mitigation and Scalability

### 13.1 Expansion Scenarios (The ”Reach” Goals)

If core mechanics are in place and we’re on pace to have extra time, we will implement

advanced signal processing features. These features involving a deeper level of processing

the ”keys” of the ”piano” to perform other outcomes.

### 13.1.1 Automatic Latency Calibration (ALC)

Currently, the user must hard-code the travelDelay variable. An expansion goal is to

automate this process.

- Concept: For each and every note, the robot will record two different positions in a

set time interval.

- Algorithm: The Arduino will determine the speed of each and every note, then

determine the timing it should take to hit the note at a specific distance.

### 13.1.2 Handling ”Long Notes” (Sustain Logic)

The Physics Problem: Long notes appear as a continuous black bar. A simple ”edge

detection” trigger would tap once at the start and then release, resulting in a failed note.

The Solution: We will modify the sensor logic to differentiate between a ”Transient

Pulse” (short tile) and a ”Steady State” (long tile). This requires rewriting the non-blocking

state machine to include a SUSTAINING state.

Listing 2: Conceptual Logic for Sustain Notes

if ( digitalRead ( COMPARATOR_PIN ) == LOW ) { // Note Detected

digitalWrite ( SOLENOID_PIN , HIGH ) ; | // Hold Down

while ( digitalRead ( COMPARATOR_PIN ) == LOW ) {

// Busy wait or state check :

// Keep holding while the black bar is passing

}

digitalWrite ( SOLENOID_PIN , LOW ) ; | // Release

}

### 13.2 De-Scope Plans (Failure Management)

Project failure often stems from the accumulation of small latencies, mechanical inertia, code

execution time, and sensor rise time. We have defined specific ”fallback” configurations if

the full high-speed game proves impossible.

### 13.2.1 Fallback A: Optical Isolation (Crosstalk Elimination)

- The Failure Mode: On small phone screens, the lanes are close together. The cone

of sensitivity of Sensor A might overlap with Lane B, causing false positives.

- The Fix: We will mechanically restrict the system to use only Lane 1 and Lane 3,

leaving Lanes 2 and 4 empty.

- Impact: This physically doubles the separation distance between active sensors, ef-

fectively eliminating optical crosstalk without requiring complex software filtering.

### 13.2.2 Fallback B: Reduced Game Speed (Kinematic Margin)

- The Failure Mode: If the solenoid inductance prevents it from retracting fast enough

for the highest difficulty levels (e.g., > 12 notes/sec).

- The Fix: We will restrict the demonstration to ”Easy” or ”Medium” difficulty settings

where note density is lower.

- Impact: This preserves the full 4-lane architecture and physics model but acknowl-

edges the thermal/magnetic limits of the specific solenoids chosen.

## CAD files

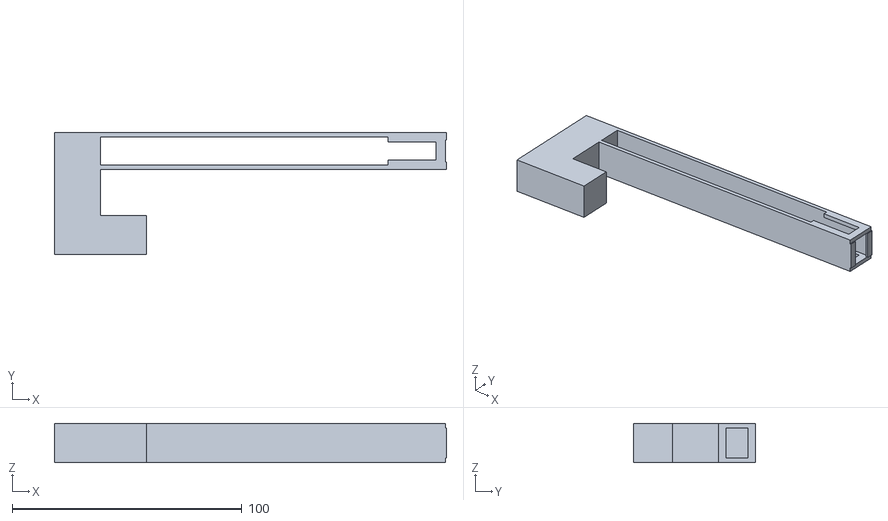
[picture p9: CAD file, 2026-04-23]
NewFinger.STL
170.5 x 53.0 x 17.0

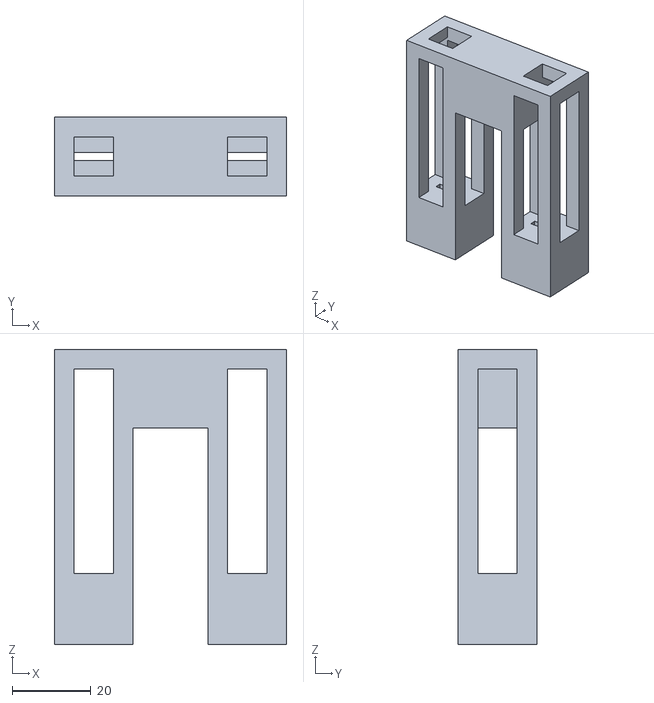
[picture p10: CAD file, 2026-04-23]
NewBridge.STL
59.0 x 20.0 x 75.0

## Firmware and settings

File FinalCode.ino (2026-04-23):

/*
 * Physics 124 Lab 4: FINAL SUBMISSION CODE
 * Status: Hardware Fixed. Logic Polished.
 * * CHANGES FROM PREVIOUS:
 * 1. Added "Startup Safety": Checks if sensor is blocked immediately on boot.
 * 2. Fixed "Restoration Timer": Uses subtraction instead of modulo (%) for reliability.
 * 3. Startup Angle: Defaults to 90 (Center) to prevent jumping to 0 on start.
 */

#include <Servo.h>

// --- Pin Setup ---
const int PIN_SERVO = 9;
const int PIN_PHOTO_LEFT = A0;
const int PIN_PHOTO_RIGHT = A1;
const int PIN_PROXIMITY = 2; 

// --- Tuning Parameters ---
const int DEAD_BAND = 15;       // Slightly higher to prevent jitter
const int SLEEP_THRESHOLD = 10; // Low threshold for dark rooms
const int MAX_STEP = 5;         // Smooth speed

Servo myServo;
int currentAngle = 90;          // Start centered (Safer than 0)

// Volatile variables for Interrupts
volatile int maxAllowedAngle = 180; 

// Timer variable for restoring range
unsigned long lastRestoreTime = 0;

void setup() {
  Serial.begin(9600);
  
  myServo.attach(PIN_SERVO);
  myServo.write(currentAngle);
  
  // Use INPUT_PULLUP to stabilize the IR signal
  pinMode(PIN_PROXIMITY, INPUT_PULLUP);
  
  // 1. INTERRUPT: Catches new objects arriving
  attachInterrupt(digitalPinToInterrupt(PIN_PROXIMITY), handleCollision, FALLING);

  // 2. STARTUP SAFETY: Checks if object is ALREADY there
  if (digitalRead(PIN_PROXIMITY) == LOW) {
    maxAllowedAngle = 90; // Limit range immediately
    Serial.println("Warning: Started with obstruction!");
  }

  Serial.println("--- SYSTEM READY ---");
}

void loop() {
  // --- A. SAFETY & RESTORATION LOGIC ---
  
  // If currently blocked, ensure we obey the limit
  if (digitalRead(PIN_PROXIMITY) == LOW) {
    if (currentAngle > maxAllowedAngle) {
       currentAngle = maxAllowedAngle;
       myServo.write(currentAngle);
    }
  }
  // If CLEAR, slowly restore range (Fixes the % bug)
  else if (maxAllowedAngle < 180) {
    if (millis() - lastRestoreTime > 100) { // Every 100ms
       maxAllowedAngle++;
       lastRestoreTime = millis();
    }
  }

  // --- B. SENSOR READING ---
  int valLeft = analogRead(PIN_PHOTO_LEFT);
  int valRight = analogRead(PIN_PHOTO_RIGHT);
  int avg = (valLeft + valRight) / 2;
  int diff = valLeft - valRight;

  // --- C. MOVEMENT LOGIC ---
  if (avg < SLEEP_THRESHOLD) {
    moveToAngle(90); // Go to sleep
  }
  else {
    if (abs(diff) > DEAD_BAND) {
      // Proportional Speed
      int stepSize = map(abs(diff), DEAD_BAND, 600, 1, MAX_STEP);
      stepSize = constrain(stepSize, 1, MAX_STEP);

      if (valLeft > valRight) {
        moveToAngle(currentAngle + stepSize); // Left
      } else {
        moveToAngle(currentAngle - stepSize); // Right
      }
    }
  }

  delay(30); // Loop speed
}

// --- Helper: Safe Move ---
void moveToAngle(int target) {
  // Enforce Dynamic Limit
  if (target > maxAllowedAngle) target = maxAllowedAngle;
  
  // Enforce Hardware Limits
  if (target < 0) target = 0;
  if (target > 180) target = 180;

  currentAngle = target;
  myServo.write(currentAngle);
}

// --- Interrupt: Emergency Stop ---
void handleCollision() {
  // Back off 20 degrees immediately
  int safePos = currentAngle - 20; 
  if (safePos < 0) safePos = 0;

  maxAllowedAngle = safePos;
  currentAngle = safePos;
  myServo.write(currentAngle);
}

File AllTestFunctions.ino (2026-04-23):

#include <Arduino.h>
#include <math.h>
#include <ctype.h>
#include <string.h>
#include <limits.h>

/*
  Project: Phys124 Computer Pianist - Unified Arduino Script
  Authors: Dylan Dahlke and Ryan Moore (original phase design)
  Generated: Feb 2026

  This single sketch includes all project functions as selectable modes:
    1) Solenoid Blink Test
    2) Comparator Tuner
    3) ISR Echo Test
    4) Solenoid One-Shot Test
    5) Latency Calibrator
    6) Variable Speed Verification
    7) Final 4-Lane Integration

  Open Serial Monitor at 115200 and type "help" for commands.
*/

// -----------------------------------------------------------------------------
// Hardware Pin Map
// -----------------------------------------------------------------------------
const uint8_t NUM_LANES = 4;
const uint8_t SOL_PINS[NUM_LANES] = {3, 5, 6, 9};
const uint8_t SENSOR_PINS[NUM_LANES] = {2, 4, 7, 8};

// -----------------------------------------------------------------------------
// User Calibration (used by Variable Speed + Final modes)
// -----------------------------------------------------------------------------
float gSensorDistMm = 40.0f;      // Distance from sensor to solenoid hit point
int gMechLagMs = 17;              // Measured mechanical lag
float gScrollSpeedMmPerMs = 0.30f; // Tile speed in mm/ms

// Final mode timing
unsigned long gFinalHoldMs = 25;
unsigned long gFinalCooldownMs = 80;
unsigned long gWatchdogMaxOnMs = 150;

// -----------------------------------------------------------------------------
// Timing constants for test modes
// -----------------------------------------------------------------------------
const unsigned long SOL_BLINK_ON_MS = 100;
const unsigned long SOL_BLINK_OFF_MS = 900;
const unsigned long COMP_TUNER_PRINT_MS = 50;
const unsigned long ONE_SHOT_HOLD_MS = 20;
const unsigned long LATENCY_TEST_DELAY_MS = 1000;
const unsigned long LATENCY_COOLDOWN_MS = 2000;
const unsigned long FINAL_ISR_DEBOUNCE_MS = 12;

// -----------------------------------------------------------------------------
// Runtime Mode Selection
// -----------------------------------------------------------------------------
enum RunMode {
  MODE_FINAL = 0,
  MODE_SOL_BLINK,
  MODE_COMP_TUNER,
  MODE_ISR_ECHO,
  MODE_ONESHOT,
  MODE_LATENCY,
  MODE_VAR_SPEED
};

volatile uint8_t gMode = MODE_FINAL;

// -----------------------------------------------------------------------------
// Final mode lane state machine
// -----------------------------------------------------------------------------
enum FinalState {
  FINAL_IDLE = 0,
  FINAL_WAITING,
  FINAL_FIRING,
  FINAL_COOLDOWN
};

struct FinalLane {
  volatile uint8_t state;
  volatile bool triggerFlag;
  volatile unsigned long detectUsIsr;
  unsigned long detectUsMain;
  unsigned long stateStartMs;
  volatile unsigned long lastEdgeMs;
  bool outputOn;
  unsigned long onSinceMs;
};

FinalLane gFinal[NUM_LANES];
bool gFinalInvalidPhysicsPrinted = false;

// -----------------------------------------------------------------------------
// Mode-specific state
// -----------------------------------------------------------------------------
// Solenoid Blink
uint8_t gBlinkLane = 0;
bool gBlinkIsOn = false;
unsigned long gBlinkChangeMs = 0;

// Comparator tuner
unsigned long gCompLastPrintMs = 0;

// ISR Echo
volatile bool gIsrEchoFlag[NUM_LANES] = {false, false, false, false};
volatile unsigned long gIsrEchoTimeUs[NUM_LANES] = {0, 0, 0, 0};

// One-shot
bool gOneShotActive[NUM_LANES] = {false, false, false, false};
unsigned long gOneShotStartMs[NUM_LANES] = {0, 0, 0, 0};

// Latency calibrator
enum LatencyState {
  LAT_IDLE = 0,
  LAT_WAIT,
  LAT_FIRE,
  LAT_COOLDOWN
};
uint8_t gLatencyState = LAT_IDLE;
volatile bool gLatencyTriggerFlag = false;
volatile unsigned long gLatencyDetectUs = 0;
unsigned long gLatencyDetectMs = 0;
unsigned long gLatencyStateMs = 0;

// Variable speed test
enum VarState {
  VAR_IDLE = 0,
  VAR_WAIT,
  VAR_FIRE
};
uint8_t gVarState = VAR_IDLE;
volatile bool gVarTriggerFlag = false;
volatile unsigned long gVarDetectUs = 0;
unsigned long gVarDetectMs = 0;
unsigned long gVarStateMs = 0;
bool gVarInvalidPhysicsPrinted = false;

// Serial command buffer
char gCmdBuffer[64];
uint8_t gCmdLen = 0;

// -----------------------------------------------------------------------------
// Pin Change Interrupt tracking
// -----------------------------------------------------------------------------
const uint8_t PORTD_WATCH_MASK = _BV(PD2) | _BV(PD4) | _BV(PD7);
const uint8_t PORTB_WATCH_MASK = _BV(PB0);
volatile uint8_t gLastPortDWatched = 0;
volatile uint8_t gLastPortBWatched = 0;

// -----------------------------------------------------------------------------
// Utility
// -----------------------------------------------------------------------------
void allSolenoidsOff() {
  for (uint8_t i = 0; i < NUM_LANES; i++) {
    digitalWrite(SOL_PINS[i], LOW);
    gOneShotActive[i] = false;
    gFinal[i].outputOn = false;
  }
}

long computeWaitDelayMs() {
  if (gScrollSpeedMmPerMs <= 0.0001f) {
    return LONG_MIN;
  }
  const float travelMs = gSensorDistMm / gScrollSpeedMmPerMs;
  const float waitMs = travelMs - (float)gMechLagMs;
  if (waitMs >= 0.0f) {
    return (long)(waitMs + 0.5f);
  }
  return (long)(waitMs - 0.5f);
}

void trimWhitespace(char *s) {
  size_t len = strlen(s);
  size_t start = 0;
  while (start < len && isspace((unsigned char)s[start])) {
    start++;
  }

  size_t end = len;
  while (end > start && isspace((unsigned char)s[end - 1])) {
    end--;
  }

  if (start > 0) {
    memmove(s, s + start, end - start);
  }
  s[end - start] = '\0';
}

void toLowerInPlace(char *s) {
  for (size_t i = 0; s[i] != '\0'; i++) {
    s[i] = (char)tolower((unsigned char)s[i]);
  }
}

bool isLaneBurst(const char *s) {
  if (s[0] == '\0') {
    return false;
  }
  for (size_t i = 0; s[i] != '\0'; i++) {
    if (s[i] < '1' || s[i] > '4') {
      return false;
    }
  }
  return true;
}

void printModeName(uint8_t mode) {
  switch (mode) {
    case MODE_SOL_BLINK:
      Serial.print(F("sol_blink"));
      return;
    case MODE_COMP_TUNER:
      Serial.print(F("comp_tuner"));
      return;
    case MODE_ISR_ECHO:
      Serial.print(F("isr_echo"));
      return;
    case MODE_ONESHOT:
      Serial.print(F("oneshot"));
      return;
    case MODE_LATENCY:
      Serial.print(F("latency"));
      return;
    case MODE_VAR_SPEED:
      Serial.print(F("speed"));
      return;
    case MODE_FINAL:
    default:
      Serial.print(F("final"));
      return;
  }
}
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
